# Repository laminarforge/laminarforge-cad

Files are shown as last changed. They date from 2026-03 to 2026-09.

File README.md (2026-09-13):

# laminarforge-cad

Parametric CAD models for the LaminarForge open-source diagnostics platform, written in Rust using the [`vcad`](https://crates.io/crates/vcad) crate. Core LAMP/CRISPR device CAD is now built around a sealed disposable diagnostic cartridge rather than loose PCR tubes. Shared constants live in `src/lib.rs`, device and validation generators live in `src/bin/`, and PCB routing lives in `src/pcb/`.

## Local iteration

Use the local `laminarforge_build` MCP tool with an explicit `bin`:

| Change | Action | Purpose |
| --- | --- | --- |
| Rust source validation | `check` | Check one target without code generation. |
| Rust source needs execution | `run`, profile `dev` | Build and run one target. |
| Runtime TOML only, executable already built from the intended source | `execute`, profile `dev` | Generate outputs without invoking Cargo. |
| Final optimized output | `run`, profile `release` | Explicitly optimize the selected target. |

The priming fixture accepts runtime TOML. Other models vary: some already read
configuration, while others use compiled constants. See [the iteration guide](docs/cad-iteration.md)
for exact tool arguments and verification requirements, and [the workflow audit](docs/cad-workflow-audit-2026-09-13.md)
for the remaining improvements.

## Source and delivery

`main` is canonical. Builds and CAD generation run locally on the Mac. AWS,
GitHub Actions and Namespace processing are retired; GitHub stores source only.
Pushing or tagging does not build or publish model outputs. Validate each
changed model and deliver its explicit output files through the local workflow.
PCB manufacturing output must also pass the [routing and release standard](docs/pcba_routing_and_release_standard.md).

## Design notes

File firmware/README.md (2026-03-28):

# LaminarForge Liquid Handler - FluidNC Firmware

ESP32-S3 firmware configuration for the 4-axis liquid handling robot.

## Hardware Overview

| Component | Specification |
|---|---|
| MCU | ESP32-S3 DevKitC |
| Drivers | 4x TMC2209 (UART mode, shared bus) |
| PSU | 24V |
| Axes | X, Y (belt), Z (geared belt 3:1), I (lead screw syringe) |

## Pin Assignments

### TMC2209 UART Bus (shared single-wire)

| Signal | GPIO |
|---|---|
| UART TX | GPIO 17 |
| UART RX | GPIO 18 |

All four TMC2209 drivers share this UART bus. Each driver is addressed individually (addr 0-3).

### X-Axis (Belt-driven gantry)

| Signal | GPIO | TMC2209 Addr |
|---|---|---|
| Step | GPIO 6 | 0 |
| Direction | GPIO 5 | |
| Enable | GPIO 7 | |
| Limit (min) | GPIO 4 | |

### Y-Axis (Belt-driven gantry)

| Signal | GPIO | TMC2209 Addr |
|---|---|---|
| Step | GPIO 8 | 1 |
| Direction | GPIO 16 | |
| Enable | GPIO 9 | |
| Limit (min) | GPIO 15 | |

### Z-Axis (Geared belt, 3:1 reduction)

| Signal | GPIO | TMC2209 Addr |
|---|---|---|
| Step | GPIO 12 | 2 |
| Direction | GPIO 11 | |
| Enable | GPIO 13 | |
| Limit (min) | GPIO 10 | |

### I-Axis (Syringe plunger, T8x2 lead screw)

| Signal | GPIO | TMC2209 Addr |
|---|---|---|
| Step | GPIO 47 | 3 |
| Direction | GPIO 21 | |
| Enable | GPIO 48 | |
| Limit (min) | GPIO 14 | |

### Auxiliary Pins

| Function | GPIO | Notes |
|---|---|---|
| Probe | GPIO 38 | ADC1-capable, for liquid level detection |
| Valve 1 (flood) | GPIO 39 | Solenoid valve control |
| Valve 2 (mist) | GPIO 40 | Solenoid valve control |
| Status LED | GPIO 41 | Digital output 0 |
| Error LED | GPIO 42 | Digital output 1 |
| I2C SDA | GPIO 1 | Reserved for sensors |
| I2C SCL | GPIO 2 | Reserved for sensors |

### Avoided Pins

The following ESP32-S3 strapping pins are intentionally NOT used:

- **GPIO 0** - Boot mode strapping pin
- **GPIO 3** - JTAG strapping pin
- **GPIO 45** - VDD_SPI voltage strapping pin
- **GPIO 46** - Boot mode / log output strapping pin

## Steps/mm Calculations

All axes use 200 steps/rev motors with 16 microsteps (3200 steps/rev).

| Axis | Mechanism | Calculation | Steps/mm |
|---|---|---|---|
| X | GT2 20T belt | 3200 / (pi x 12.73mm) = 3200 / 39.98 | **80.04** |
| Y | GT2 20T belt | Same as X | **80.04** |
| Z | GT2 20T + 3:1 gear | 80.04 x 3 | **240.12** |
| I | T8x2 lead screw | 3200 / 2mm lead | **1600.00** |

## Syringe Calibration

Hamilton 1710RN 100uL syringe:

- Barrel inner diameter: 1.46mm
- Barrel cross-section area: pi x (0.73)^2 = 1.674 mm^2
- Travel per microliter: 1 mm^3 / 1.674 mm^2 = **0.597 mm/uL**
- 30mm mechanical travel = ~50.2 uL usable volume
- 1 step = 1/1600 mm = 0.000625 mm = **0.00105 uL** (sub-nanoliter resolution)

## Motion Parameters

| Axis | Max Speed | Acceleration | Max Travel |
|---|---|---|---|
| X | 100 mm/s (6000 mm/min) | 500 mm/s^2 | 300 mm |
| Y | 100 mm/s (6000 mm/min) | 500 mm/s^2 | 300 mm |
| Z | 50 mm/s (3000 mm/min) | 200 mm/s^2 | 100 mm |
| I | 5 mm/s (300 mm/min) | 100 mm/s^2 | 30 mm |

The I-axis uses deliberately low acceleration and speed to prevent bubble formation and ensure precise dispensing.

## Homing Sequence

All axes home to their minimum (negative) position in this order:

1. **Cycle 1 - X-axis**: Homes to min via microswitch on GPIO 4
2. **Cycle 2 - Y-axis**: Homes to min via microswitch on GPIO 15
3. **Cycle 3 - Z-axis**: Homes to min (retracted/up) via microswitch on GPIO 10
4. **Cycle 4 - I-axis**: Homes to min (plunger fully retracted) via microswitch on GPIO 14

Z homes before I so the pipette tip is safely raised before the syringe retracts. The I-axis uses a very slow homing speed (1 mm/s feed) to avoid damaging the syringe or creating excessive vacuum.

## Flashing FluidNC to ESP32-S3

### Prerequisites

- Python 3.8+
- `esptool.py` (`pip install esptool`)
- FluidNC firmware binary (download from [FluidNC releases](https://github.com/bdring/FluidNC/releases))
- USB-C cable connected to ESP32-S3 DevKitC

### Step 1: Erase flash

```bash
esptool.py --chip esp32s3 --port /dev/tty.usbmodem* erase_flash
```

### Step 2: Flash FluidNC firmware

```bash
esptool.py --chip esp32s3 --port /dev/tty.usbmodem* \
  --baud 460800 \
  write_flash \
  0x0000 bootloader.bin \
  0x8000 partitions.bin \
  0x10000 firmware.bin \
  0x3d0000 spiffs.bin
```

Alternatively, use the FluidNC WebUI installer at [http://install.fluidnc.com](http://install.fluidnc.com) for a browser-based flash.

### Step 3: Upload configuration

1. Connect to the `LaminarForge` WiFi AP (password: `laminarforge`)
2. Open `http://192.168.0.1` in a browser
3. Navigate to the **Files** tab in the FluidNC WebUI
4. Upload `fluidnc_config.yaml` as the machine config
5. Restart the ESP32 (or send `$Bye` then power cycle)

Alternatively, upload via serial:

```bash
# Using FluidNC's built-in file upload over serial
# Connect at 115200 baud, then use $LocalFS/Upload command
picocom -b 115200 /dev/tty.usbmodem*
```

### Step 4: Verify

After reboot, connect via serial or WebUI and check:

```
$SS   # Show settings summary
$$    # Show all settings
$H    # Home all axes (ensure limit switches are wired)
?     # Status report
```

## TMC2209 UART Wiring

The four TMC2209 drivers share a single UART bus. Each driver must have its
address pins (MS1, MS2) set to give it a unique address:

| Driver | Axis | MS1 | MS2 | Address |
|---|---|-----|-----|---|
| U1 | X | LOW | LOW | 0 |
| U2 | Y | HIGH | LOW | 1 |
| U3 | Z | LOW | HIGH | 2 |
| U4 | I | HIGH | HIGH | 3 |

The UART TX pin connects to all four PDN_UART pins through 1k ohm resistors.
The UART RX pin connects to all four PDN_UART pins directly (active-low
open-drain outputs on the TMC2209 side).

## Troubleshooting

- **Motors don't move**: Check 24V supply, verify enable pins are being driven LOW (active low on TMC2209)
- **Erratic motion**: Verify UART addresses match MS1/MS2 pin settings on each driver
- **Homing fails**: Check limit switch wiring (normally open, pulled up internally). Verify with `?` status that switch state changes when actuated
- **Syringe stalls**: Reduce I-axis run current or increase stallguard threshold. The lead screw has inherent friction that can trigger false stall detection
- **WiFi won't connect**: The AP defaults to `LaminarForge` / `laminarforge`. If reconfigured for STA mode, check SSID and password in the YAML

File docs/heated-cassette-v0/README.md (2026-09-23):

# LaminarForge heated microplate cassette V0 - Rev D

This package defines one manual, two-zone heated aluminum cassette for water-filled microplate temperature testing. Manufacture to the analytic STEP files together with the shop drawings and manufacturing notes. STLs and assembly images are viewing aids. The physical prototype still needs commissioning and temperature mapping.

Greiner 655101 with lid 656101 is the selected inexpensive thermal surrogate. It is not a perfused tissue-on-chip plate. No live-cell suitability, sterile atmosphere, humidity control, CO2 control, hermetic seal, rocking endurance or media-temperature performance is certified here.

## Fabrication and assembly

Send the complete supplier RFQ ZIP, including assembly-drawings.pdf, the numbered assembly/manufacturing BOMs, shop-drawings.pdf and the assembly handbook, to a CNC shop. Request one set, 6061-T6, including clear Type II finishing and the limited fit-dimension report. Buy the commercial mechanical/electrical parts from the BOM. Assembly needs metric hex tools, a small torque driver, multimeter, suitable connector crimp tooling, solder/heat-shrink supplies and temperature-measurement equipment.

One representative spacer file specifies eight identical spacers. Both guards, both risers and both cable jaws are identical after translation. The left guide rail has an extra stop-access hole. The cable-bracket bases differ.

## Design definition

- Four-piece bolted frame (roof, left/right side plates, front bezel), rear cover, heated sliding bottom, front flange and removable nest.
- Two manual M4 closure knobs; continuous silicone face gasket; metal face-to-face closing stop.
- Two 100 x 100 mm, 24 V, 60 W heaters with separate Pt100 sensors, PIDs and DC SSRs.
- Independent NC thermostats drop latched power relays. Shared STOP and separate zone RESET buttons.
- Guide tape on edges only. The plate sits directly on the aluminum drawer.
- Rearward R35 cable loops and 30 mm bench risers; keep the service bay clear.

Housing/flange envelope: 197.26 W x 176.73 D x 75.225 H mm. Complete bench assembly is approximately 95.225 mm high, Z=-30 to +65.225 including upper screw heads. Reserve 120 mm forward of the closed front for drawer access and space through Y=270 behind the assembly datum for cable travel. Closed outer front is Y=-8. Controller box and power brick are separate.

The closure knobs project another 11.5 mm forward and remain within the wider 197.26 mm flange width. With the reserved rear cable bay, allow approximately 290 mm closed bench depth, plus the forward drawer-access space. See the generated thermal-sizing.json for the current aluminum mass. This is a bench arrangement, not a finalized rack pitch.

Nominal stroke is 107.73 mm. Rear aluminum capture is 45 mm; the shortened left upper tape retains 29 mm overlap. The flange defines closing position. The stop slot allows approximately 0.2 mm pin clearance beyond nominal travel.

## Plate fit

Greiner's 655101 drawing specifies 127.76 +/-0.20 x 85.48 +/-0.20 mm footprint and 14.6 +/-0.1 mm lidless height. The nest opening is 129.26 x 86.98 mm with corner reliefs. Minimum centered side clearance is 0.65 mm at the plate's upper tolerance, before nest manufacturing tolerance.

Lid 656101 is 127.5 +/-0.2 x 85.0 +/-0.2 mm. Its drawing shows 10 mm overall lid features but does not certify assembled plate/lid height. This design reserves a 26 mm lidded object plus 8 mm roof clearance. The 26 mm value is a design allowance, not the actual Greiner assembled height. Measure the delivered lidded plate. Future tissue plates need separate exterior, lid, port, orientation, access and rocking checks.

## Rev D changes

Rev D replaces the unsent integral Rev C housing with four bolted plates. Side plates finish at 18.50 mm from nominal 3/4-inch stock; roof and bezel finish at 6 mm from 1/4-inch stock. The body grows 12.50 mm in width while the drawer, plate clearances and stroke remain unchanged. Six roof screws, four recessed bezel screws and six locating dowels join the frame. Assembly drawings, BOMs and individual STEP files describe the separate parts. Joint contact resistance and thermal behavior require physical commissioning.

Rev A hardcoat is superseded by clear sealed Type II anodizing, 5-15 micrometers. The quote covers 26 aluminum pieces in 16 designs per set. Foam, backing, guide tape, hardware and electronics are owner supplied. Per-part prices and a separate finishing charge are sufficient; operation-level costing is not required. The integral housing is replaced by four plates, located by dowels and fastened with M3 screws.

## Verification and file precedence

The generator uses one construction tree for analytic STEP and review meshes. It reimports every custom STEP, checks one manifold solid, compares volumes and records hashes. It checks closed meshes and sampled moving/fixed interference. Packaging separately imports every supplied STEP into the installed Open CASCADE DRAW checker, checks exact shape validity and one solid, and retains the result logs. This is a separate version/import path, not proof that every supplier CAD system will accept the file. These checks do not establish fatigue, deformable-part behavior, process capability or electrical certification.

The reduced thermal model estimates steady aluminum-sheet conduction over assumed heat-loss/conductivity cases. It does not resolve media, plastic wells, evaporation, airflow or PID transients. Water measurements decide thermal acceptance.

Use configuration, verification manifest, STEP and drawings from the same release. Explicit thread and manufacturing notes control where STEP represents pilot bores; paired STEP controls other geometry. Resolve conflicting instructions before cutting an affected part. Integrated mechanical instructions supersede preliminary research arrangements.

## Sources

Plate: https://hamptonresearch.com/uploads/support_materials/HR3-139_Greiner_655101_customer_drawing.pdf

Lid: https://shop.gbo.com/en/usa/products/bioscience/lids-sealers-capmats/lids/656101.html

Lid drawing: https://www.bunzlasiapacific.com/extension/IP/document_896_5bfca99a5b406.pdf

Component sources are linked in the BOM/electrical appendices. Prices are snapshots, not a complete landed cost or a CNC quote.

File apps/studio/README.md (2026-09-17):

# LaminarForge Studio

Local macOS design review app written in Rust. Open a folder of generated STL
files, search the library, inspect a mesh, and export the current view as PNG.
The app uses an OpenGL depth buffer and GPU triangle rendering through eframe.
It requires macOS 12 or later. Build on the target Mac architecture.

## Use

- Select **Funding** to edit the prototype grant proposal, expense budget and submission checklist. The initial application ships with the app.
- Funding edits persist locally, including in the sandboxed TestFlight app. Use
  **Save changes** to save immediately; normal autosave runs every five seconds and
  on app exit. Funding content is independent of CAD folder permissions.
- Copy individual application fields and open the provider form when ready.
  The app does not submit applications. The initial round covers fabrication, assembly and water-based thermal validation; no lab access is required. Budget allowances are provisional.
- **Supplier quotes and equipment prices** shows dated research, source links,
  sent RFQ threads and unresolved costs. The catalog subtotal excludes unpriced
  items and optional candidates. It does not replace the complete funding budget.
  This bundled snapshot is refreshed with app updates independently of saved
  proposal edits; it does not poll Gmail or automatically send follow-ups.

- Open **LaminarForge Studio.app**, then **Open folder…** or **Open design…**.
- A dropped STL file or directory also opens in the workspace.
- Drag to orbit; right/middle drag to pan; scroll to zoom.
- Press **F**, double-click the viewport, or use **Fit design** to reframe.
- Choose shaded, shaded with edges, or hidden-surface wireframe.
- Use the inspector for orthographic projection and top/front/isometric views.
- **Export PNG…** saves only the render viewport at its current pixel size.
- **Refresh library** rescans disk; **Reload design** reloads changed geometry.

The local development app remembers its library and design. The sandboxed
TestFlight app starts with an empty library each launch; select a folder or file
with the Open controls to grant access for that session. There is no network service,
cloud processing, or account requirement. Diagnostics use structured tracing on
stderr. An optional first CLI argument opens a file or folder at launch.

## Supported geometry

ASCII and binary STL are supported. Files are never modified. Bounds report
source coordinate units: STL does not record units; LaminarForge generators
normally use millimeters. Invalid files and non-finite coordinates report errors.
Zero-area faces are omitted and counted. Limits are 150 MB per file, two million
triangles, 10,000 library files and 16 folder levels. Directory scans skip symbolic
links, hidden folders, target and node_modules. Permission failures are explicit.

This first version renders existing meshes. It does not edit CAD parameters,
generate new geometry, import STEP directly, or validate manufacturing readiness.
Generate STL with the existing CAD tools before opening it here.

## Local build and delivery

This is a separate Cargo package so desktop dependencies do not affect the CAD
generators. Use `laminarforge_build` with `repo: "laminarforge-cad"`, `repo_path`
set to this `apps/studio` directory, `bin: "laminarforge_studio"` and action
`check` or `build`. Select `profile: "dev"` for iteration. Cargo.lock is tracked.

For a local app bundle, use the same MCP tool with `bin: "studio_bundle"`, action
`run`, and args `[BUILT_STUDIO_EXECUTABLE, NEW_OUTPUT_APP_PATH]`. The packager
creates the icon, plist and executable, ad-hoc signs the bundle, and verifies
the signature. Output must be a fresh `.app` path. This is a local Mac build,
not an Apple-notarized download or a TestFlight release.

For parser tests, run `cargo test --locked --bin laminarforge_studio -j 2` from
this directory; the CAD MCP currently exposes no test action.

To verify actual GPU rendering use MCP `run`, `background: true`, with args:

```text
--render-check INPUT_STL_OR_FOLDER FRESH_OUTPUT.png edges
```

The last argument is optional: `shaded`, `edges`, or `wireframe`. This opens the
real window, loads the geometry, captures the rendered framebuffer, writes the
viewport PNG plus `FRESH_OUTPUT.workspace.png`, and exits. A missing PNG is an
error. Inspect the capture as well as the exact background job status. Use a
fresh output filename for every check. UI automation and full interaction tests
remain separate from the framebuffer check.

## TestFlight

The macOS target in `project.yml` packages the Rust executable for Apple Silicon.
Build `laminarforge_studio` with the local CAD MCP and `features: ["app-store"]`.
Stage that build receipt's executable as `dist/laminarforge_studio` and generate
`dist/laminarforge_studio.sha256` using `shasum -a 256 laminarforge_studio` from
`dist`. Xcode verifies the checksum before installing the executable into its
app bundle, then signs with the Studio Mac App Store provisioning profile.
The profile and signing credentials are machine configuration, never repository
files. `ExportOptions.plist` selects App Store Connect distribution.

Submit with `macos_deploy`, app `laminarforge-studio-macos`. The Mac-local
pipeline allocates the build number, generates the Xcode project, archives,
exports the signed installer and uploads to TestFlight. No cloud build is used.

The initial verification used the heated-cassette V0 design library (20 files)
and closed/open assemblies. The closed assembly rendered 11,866 triangles.
Desktop-control verification was unavailable because the Sky native pipe failed
to start; framebuffer verification exercised actual native rendering and export.

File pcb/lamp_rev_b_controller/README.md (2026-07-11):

# LAMP Rev B Controller PCBA

Source-package ticket: `T-4C206871`<br>
Manufacturer-handoff ticket: `T-E36FA2C2`<br>
Electrical release evidence: `A-9F7C4851`

This directory is the deterministic source for the Rev B controller carrier. The promoted copper/electrical design is fabrication-clean. Manufacturer-order readiness is a separate fail-closed state owned by `lamp_rev_b_controller_fab_release`.

## Routing and release policy

All routing and manufacturer-release work is governed by the mandatory [LaminarForge PCBA Routing and Release Standard](../../docs/pcba_routing_and_release_standard.md). The board-specific fixture and evidence are:

- [`freerouting_benchmark.toml`](freerouting_benchmark.toml): pinned router/tool settings and the 1,200-second runtime cap;
- [`freerouting_benchmark.md`](freerouting_benchmark.md): harness operation and determinism limitations;
- [`benchmarks/freerouting_v2_1_0_pass_sweep.md`](benchmarks/freerouting_v2_1_0_pass_sweep.md) and its [JSON record](benchmarks/freerouting_v2_1_0_pass_sweep.json): exact 1→10→50 matrix evidence;
- [`benchmarks/freerouting_v2_1_0_promotion.md`](benchmarks/freerouting_v2_1_0_promotion.md): first-clean promotion-attempt evidence; and
- [`electrical_release_evidence.md`](electrical_release_evidence.md), [`fab_release.toml`](fab_release.toml), and [`release_manifest.toml`](release_manifest.toml): electrical, fabrication, and deterministic-package gates.

These files specialize the general policy for Rev B; they do not replace it. Routing and SES validation remain scratch-only until every promotion gate passes.

## Locked first-article population

- Variant: `rev_b_12v_first_article`; 5 assembled top-side PCBAs.
- `R25` and `R26`: mandatory DNP. Populating either bypasses its heater MOSFET and can energize the heater whenever `VIN_HEATER` is present.
- `R55`: populate only for this 12 V variant; DNP for 24 V unless an approved regulated 12 V VDRV path is present.
- `J24`: connect through an external normally-closed thermal cutoff or a correctly rated jumper before heater tests. Do not bridge `VIN_PROTECTED` to `VIN_HEATER` in copper.
- `LDD-1000H` and `P7812-500R` alternates: DNP for this release.
- Panelization: fabricator-owned from the released single-up board; portal preview approval is mandatory.

## Authoritative workflow

Run the repository contract and release command through the LaminarForge build tool:

```json
{"repo":"laminarforge-cad","action":"run","bin":"lamp_rev_b_controller_check"}
```

```json
{"repo":"laminarforge-cad","action":"run","bin":"lamp_rev_b_controller_fab_release"}
```

The release command requires a clean full commit equal to `origin/main` and KiCad `10.0.3`. It writes every KiCad report/export to two ignored temporary trees, normalizes known time metadata, compares every staged byte, and promotes only identical results.

When every external choice is controlled, it emits:

- nine fabrication Gerbers plus the Gerber job file;
- separate F/B paste Gerbers;
- separate PTH/NPTH Excellon drills, both drill maps, and drill report;
- fabrication and top/bottom assembly PDFs;
- formal BOM, CPL, DNP, and no-substitution CSVs;
- schematic PDF, top/bottom renders, board-only mechanical STEP, source snapshot, notes, and electrical evidence;
- `MANIFEST.json`, `SHA256SUMS`, upload units, and a normalized outer handoff ZIP.

If procurement, stackup/order fields, or portal approval remain unresolved, it still preserves the byte-reproducible review tree and exact blocker report, exits nonzero, and emits neither `upload/` nor the outer handoff ZIP.

## Current external blockers

Repository evidence does not define a selected manufacturer/order profile, physical dielectric stackup, fabrication tolerances/class, final finish specification, colors, or an impedance-policy decision. `parts.toml` also lacks explicit manufacturer/MPN fields and contains unresolved supplier prose/manual selections. No portal preview has been approved. These are manufacturing choices, not electrical design defects; do not invent them and do not treat the provisional artifact `A-D87AC12B` as vendor-cited research.

Any source, population, placement, schematic, stackup, or copper change invalidates prior evidence and requires fresh DRC/connectivity/ERC/BOM/CPL/reproducibility gates.

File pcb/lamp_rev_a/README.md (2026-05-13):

# LaminarForge LAMP Rev A PCBA

This directory is the source package for the real one-board LAMP PCBA.

The goal is one 4-layer ESP32-S3 board that can be checked, laid out in KiCad,
exported for JLCPCB, and iterated without going back to the old generated-layout
workflow.

## Source Of Truth

- `contract.toml`: board requirements, rails, nets, GPIO map, test points, and verification gates.
- `parts.toml`: selected schematic parts plus explicit fab-blocking part-selection gaps.
- `power_architecture.toml`: locked Rev A power topology and the explicit no-buck decision.
- `optical_architecture.toml`: locked Rev A optical topology, wavelength, detector, and front-end decision.
- `optical_mode.md`: human-readable optical-mode decision and bench validation gate.
- `placement.toml`: locked starting refs, coordinates, test points, and eight-slot optical geometry.
- `pin_nets.toml`: conservative footprint pad-to-net assignments for known package pinouts.
- `firmware_handoff.toml`: ESP32-S3 module-pin to SoC-GPIO handoff, slot map, and firmware bring-up notes.
- `electrical_validation.toml`: pre-fab electrical validation assumptions, derating gates, current-path checks, and simulation handoff sources.
- `routing_plan.toml`: routing phase order, current unrouted count, autorouter policy, and release gates.
- `routing_seed.toml`: DRC-clean starter traces emitted into the materialized board.
- `copper_zones.toml`: controlled KiCad copper pours, starting with front/back GND zones.
- `fab_release.toml`: repeatable KiCad CLI export contract for Gerbers, drill files, assembly files, STEP, and release reports.
- `lamp_rev_a.kicad_sch`: KiCad schematic shell for the one-board Rev A electrical architecture.
- `lamp_rev_a.kicad_pcb`: materialized KiCad board with the Rev A outline, 4-layer stack, placed footprints, test points, and optical-slot guides.
- `lamp_rev_a.kicad_pro`: KiCad project shell.
- `sym-lib-table` / `fp-lib-table`: project-local library tables pointing at the locked `pcb/lib/lcsc` symbols and footprints.
- `lamp_rev_a.kicad_dru`: custom KiCad design rules for power, heater, analog, and USB constraints.
- `kibot.yaml`: intended fab/report export pipeline once the schematic and placed board exist.

Rust should validate contracts and automate exports. KiCad should own the
schematic and PCB layout.

## Iteration Flow

```text
contract.toml + parts.toml
  -> cargo run --release --bin lamp_pcba_check
  -> placement.toml refs and zone checks
  -> pin_nets.toml trusted pad assignments
  -> firmware_handoff.toml firmware pin/slot handoff checks
  -> electrical_validation.toml power, derating, heater, GPIO, USB, and simulation checks
  -> cargo run --release --bin lamp_rev_a_materialize_board
  -> cargo run --release --bin lamp_rev_a_seed_routes_from_drc when reseeding short safe traces
  -> cargo run --release --bin lamp_rev_a_route_greedy for DRC-gated route iteration
  -> kicad-cli pcb drc --refill-zones for zone-connected routing checks
  -> KiCad schematic capture in lamp_rev_a.kicad_sch
  -> KiCad ERC
  -> footprint/BOM/JLC field lock
  -> KiCad placement cleanup from the materialized board
  -> KiCad interactive routing
  -> KiCad DRC + schematic/PCB parity
  -> KiBot/KiKit fab outputs
  -> physical bring-up measurements
  -> update contract.toml for the next revision
```

## Board Decisions

- One physical board for Rev A.
- 4-layer stack: `F.Cu`, `In1.Cu` ground plane, `In2.Cu` power plane, `B.Cu`.
- ESP32-S3 module, not a bare ESP32 chip.
- USB VBUS is the Rev A electronics 5 V source through a Schottky path; +3V3 is derived locally.
- The 12 V input is reserved for heater power. Do not add a 12 V to 5 V buck unless standalone non-USB operation becomes a new explicit Rev change.
- External heater element driven from the board through a protected high-current output.
- Heater path protection is locked as board-side resettable fuse + TVS + 5.08 mm heater terminal, with an external inline KSD9700 thermal cutoff mounted on the heater assembly.
- Optical mode is locked to 650 nm red-light turbidimetry with eight LED/photodiode channels, muxed into one TIA and ADC path.
- Starting placement is locked in `placement.toml`: 91 top-side footprints, 16 test points, and 8 optical slots at 12 mm pitch.
- Test points are mandatory for rails, heater control/output, I2C, UART, boot/reset, ADC, and mux output.

## Local Checks

Run:

```bash
cargo run --release --bin lamp_pcba_check
cargo run --release --bin lamp_rev_a_electrical_validate
cargo run --release --bin lamp_rev_a_spice_check
cargo run --release --bin lamp_rev_a_materialize_board
cargo run --release --bin lamp_rev_a_fab_preview
cargo run --release --bin lamp_rev_a_fab_release
cargo run --release --bin lamp_rev_a_route_report
cargo build --release --bin lamp_rev_a_materialize_board --bin lamp_rev_a_route_greedy
LAMP_ROUTE_MAX_ACCEPTS=10 LAMP_ROUTE_MAX_TRIALS=160 target/release/lamp_rev_a_route_greedy
```

`lamp_rev_a_spice_check` requires `ngspice`. `main` CI installs it, runs the
operating-point check against the generated power-path netlist, then runs
`lamp_rev_a_fab_release` on a KiCad-enabled macOS runner and uploads
`lamp-rev-a-pcba-fab-release-<commit>` containing the validated fab release
directory and upload bundles.

The current schematic is an architecture shell, not a fabrication-ready circuit.
The checker should not report fab-blocking part-selection gaps. The board now
materializes all selected parts into KiCad with zero physical DRC violations
with a DRC-clean starter route seed and GND copper pours. The route seed is
currently at 112 accepted segments, zero real unrouted ratlines after KiCad zone
refill, and one ignored KiCad self-zone report item for the front GND pour. The
active work is schematic completion, schematic/PCB parity, fab export validation,
and bench validation.
`lamp_rev_a_fab_release` emits JLCPCB machine-assembly BOM/CPL files separately
from through-hole/manual-install parts, then verifies that required Gerbers,
drills, reports, position files, review STEP output, and the order audit report
are present and non-empty. It also emits validated upload bundles under
`fab_release/bundles/`: fabrication Gerbers/drills, assembly CSVs, and review
artifacts. The release also includes a source snapshot bundle with the exact
KiCad and TOML inputs used to generate the fab package. The review package
includes a bring-up checklist generated from the configured Rev A test points
and a firmware handoff generated from the checked ESP32-S3 pin map. It also
emits an electrical-validation report, a first-order SPICE power-path handoff,
a machine-checked full-speed USB DP/DN routing sanity gate, a
simulation/analysis handoff, generated PDN current-path and thermal power CSVs,
a structured first-article measurement CSV for current-limited rail bring-up,
component derating/stress CSVs for the high-risk electrical parts,
an EMC/ESD pre-compliance CSV for USB, heater, 12 V, Wi-Fi, and analog noise risks,
a USB-C power-budget CSV for Rd/default-current, VBUS/+5V/+3V3 current, inrush linkage, and first-article rail coverage,
a procurement-readiness CSV for critical part ordering, machine/manual assembly, and external safety-component evidence,
a procurement-substitution CSV locking safety-critical LCSC order codes and requiring engineering review for swaps,
a schematic source/parity CSV tying the architecture-shell KiCad schematic to contract modules, selected parts, and required nets,
a connector/polarity CSV for USB-C, manual connectors, diodes, MOSFETs, and orientation-sensitive IC pinouts,
an assembly-orientation CSV for machine-placed ICs, polarity-sensitive parts, CPL centroids, and pin-1 evidence,
an assembly-inspection CSV requiring AOI/photo evidence, linked validation gates, and stop/rework actions for critical parts,
an assembly-fixture/readability CSV requiring visible silkscreen labels, fixture references, photo evidence, and rework actions for critical connectors/test points,
a machine-checked assembly-parity CSV for BOM/CPL/manual/position reference consistency,
a fabrication-capability CSV for board-house stackup, geometry, drill, via, and routing process limits,
an I2C/ADS1115 bus validation CSV for pull-up, rise-time, device identity, and stuck-low coverage,
a heater-protection coordination CSV for PTC, terminal, MOSFET, TVS, external cutoff, and current-limit coverage,
an external-harness safety CSV for 12 V adapter, heater leads, inline cutoff, wire gauge, polarity, and strain relief,
a mechanical-access CSV for service connector, heater terminal, MOSFET, boot/reset, analog, and I2C probe reachability,
an ESP32-S3 startup-safety CSV for boot straps, reset, and heater fail-closed defaults,
a manufacturing-test coverage CSV for critical test points, firmware diagnostics, and release traceability,
a calibration-readiness CSV for heater, ADC, optical, sensor-bus, negative-control, and firmware identity records,
a validation-traceability CSV tying each gate to artifacts, manifest evidence, CI steps, and pass criteria,
a simulation-input CSV for PDN, electrothermal, USB/SI, and EMC handoff readiness,
the first routed-geometry DC PDN simulation CSV for voltage drop and I2R loss,
a lumped thermal-margin simulation CSV for component and routed-copper steady-state estimates,
a heater/reaction-block thermal transient CSV for warm-up, hold, duty, overshoot, and energy estimates,
an ngspice ESP32-S3 reset/boot-strap timing netlist/CSV for EN, GPIO0, and boot-sensitive output startup checks,
an ngspice USB/VBUS hot-plug and 3.3 V startup/inrush netlist/CSV for rail startup envelope checks,
an ngspice 3.3 V rail load-step transient netlist/CSV for ESP32 burst-load sag,
an ngspice power-domain fault/backfeed netlist/CSV for 12 V heater-domain isolation assumptions,
an ngspice optical analog front-end transient netlist/CSV for TIA/ADC signal-envelope range,
an optical crosstalk/mux-settling CSV for slot isolation and ADC sampling assumptions,
an optical signal/noise margin CSV for threshold and negative-control drift assumptions,
and a thermistor/ADC transfer CSV for heater temperature-sense range, sensitivity, and fault coverage,
and a checksum manifest for the fabrication, assembly, and source bundles.
It also mirrors the board STEP review model to `output/lamp_rev_a_board.stp`;
run the CAD conversion for `lamp_rev_a_board` to create
`output/lamp_rev_a_board.usdz` for the Agentic FlowState CAD tab.

Current KiCad checks:

```bash
kicad-cli sch erc pcb/lamp_rev_a/lamp_rev_a.kicad_sch \
  -o pcb/lamp_rev_a/reports/erc.json --format json

kicad-cli pcb drc --refill-zones --format json \
  --output pcb/lamp_rev_a/reports/drc.json \
  pcb/lamp_rev_a/lamp_rev_a.kicad_pcb
```

Expected DRC state at this stage: `0 violations` and no real unrouted
connections. KiCad may still report one self-referential front-GND-zone
`unconnected_items` entry; `lamp_rev_a_route_report` ignores only that exact
self-zone artifact and still reports real ratlines by net.

`lamp_rev_a_seed_routes_from_drc` is intentionally conservative: it only seeds
short direct routes that preserve zero physical DRC violations. Longer routes
must be added deliberately in `routing_seed.toml`, accepted by
`lamp_rev_a_route_greedy`, or finished in KiCad. `lamp_rev_a_route_greedy`
mechanically tries candidate routes, runs KiCad DRC, and keeps only candidates
that reduce `unconnected_items` while preserving zero physical DRC violations.

Do not accept autorouter output by itself. Use it to expose bad placement or
constraint problems, then finish and review the layout in KiCad.

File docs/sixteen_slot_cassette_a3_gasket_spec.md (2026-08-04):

# 16-Slot Cassette A3 Gasket Subsystem Spec

Ticket: T-3ABDE2C9

This is the gasket subsystem specification for the first physical LaminarForge 16-slot AAV cassette build. It is subordinate to `docs/sixteen_slot_cassette_a0_interface_spec.md`; if this document conflicts with A0, A0 controls until the cassette integrator updates the interface contract.

This is not a sterile-barrier claim, biological release criterion, or final production drawing. It defines the first-article gasket geometry, material candidates, compression evidence, and no-cell validation gates needed before manufacturer drawings and live-cell/AAV work.

## Scope Boundary

A3 owns:

- Per-slot and perimeter gasket material direction.
- Gasket cross-section and locked nominal lid-groove dimensions.
- Compression target, compression stops, and witness shims/coupons.
- Gasket land surface finish, flatness, and cleaning-inspection assumptions.
- No-cell leak, coupon burst, and repeated gasket reassembly validation logic.
- Gasket-specific open decisions for integrator, A2 lid/clamp, A4 DFM, and validation agents.

A3 does not own carrier architecture, lid/clamp layout, disposable tubing route, port family, incubation control, or final CAD generator edits except where those features directly set gasket compression, retention, or test interfaces.

## A0 Interface Inputs

The gasket design uses these A0 locked inputs:

| Interface | A0 value |
| --- | ---: |
| Cassette format | 16 slots, 4 x 4 |
| Experimental unit | One cassette equals one AAV capsid/promoter/payload/dose/timing/media condition; seal loops do not authorize separate per-slot candidates. |
| Active CAD baseline | `sixteen_slot_cassette_incubator_first_article` |
| Carrier base body / true overall | 699.04 x 541.92 x 24.00 mm / 699.04 x 541.92 x 31.35 mm |
| Per-slot gasket land outer | 145.76 x 103.48 mm |
| Per-slot gasket land inner | 129.76 x 87.48 mm |
| Per-slot gasket land wall width | 8.00 mm |
| Per-slot gasket land height | 7.35 mm above carrier top; land face meets lid underside at closure. |
| Inter-land clearance | 6.00 mm between adjacent outer edges; all 16 loops are independent and nonoverlapping. |
| Perimeter gasket land outer | 629.04 x 459.92 mm |
| Perimeter gasket land inner | 605.04 x 435.92 mm |
| Perimeter gasket land wall width | 12.00 mm |
| Perimeter gasket land height | 7.35 mm above carrier top; common with per-slot lands and hard stops. |
| Nominal chip protrusion / closure plane | 7.35 mm above carrier top |
| Nominal gasket thickness | 2.40 mm |
| Lid groove cavity | 1.80 mm deep x 3.20 mm wide |
| Target squeeze | 25% |
| Squeeze guard band | 20-30% |
| Witness steps | 20%, 25%, 30% |
| Hard stops | Nine 4.00 mm-diameter internal stops at the 3 x 3 inter-slot intersections plus 4.00 mm-wide perimeter stops in the 5.00 mm seal-to-gutter web; all top at 7.35 mm and clear every seal. |

First-article wetted-path policy remains unchanged: disposable commercial tubing/connectors are the culture-fluid boundary. Structural cassette parts and A3 gaskets are dry structural/environmental seals unless separately validated as wetted, cell-facing, and AAV-compatible interfaces.

## Target Seal Architecture

Use controlled-compression axial face seals, not adhesive-only sealing.

The first-article gasket is a replaceable continuous elastomer seal seated in machined grooves on the lid/clamp compression side and compressed against the raised carrier gasket lands. This keeps the carrier land surfaces simple to inspect and lets the lid carry gasket retention features. At closure, the 7.35 mm carrier land faces meet the lid underside and the 1.80 mm groove cavities contain the compressed gasket; the groove location is no longer an optional A2 inversion.

Recommended first-article architecture:

| Seal loop | Function | Direction |
| --- | --- | --- |
| 16 per-slot loops | Local chip-pocket/environmental isolation and visible leak segregation by slot | One continuous loop per slot, seated over the A0 per-slot raised land. |
| Perimeter loop | Outer condensate/leak containment and environmental boundary | One continuous loop on the A0 perimeter land; do not treat this as a high-pressure chamber boundary until structural proof is complete. |
| Witness coupon loops | Process and material evidence | Same cross-section, gland depth, finish, and compression stops as production loops. |

Avoid discrete corner pieces, butt joints, hand-cut square gasket corners, or RTV-in-place sealing for the first article. If spliced cord is used, splice joints must be vendor-made or made with a documented fixture and placed on straight segments away from ports, drains, and high-observation zones.

## Material Candidates

The first material downselect is between high-purity silicone and high-purity EPDM. TPE/SEBS remains a research-backed option for integrated organ-chip microgaskets, not the default reusable cassette face seal until vendor review.

| Rank | Material | Use case | Advantages | Risks / limits | A3 disposition |
| ---: | --- | --- | --- | --- | --- |
| 1 | Platinum-cured silicone, 50-60 Shore A, USP Class VI / ISO 10993 supplier data preferred | First dry/environmental cassette gasket and witness coupons | Common medical/bioprocess gasket material, tolerant of 37 C humid incubation, available as molded seals or cord, low closure force versus harder elastomers | Gas permeability; possible absorption/adsorption if used as wetted drug/vector-contact surface; tear risk at thin sections | Baseline candidate for first quote and no-cell validation. Not approved for AAV/culture-fluid contact without extractables/adsorption review. |
| 2 | High-purity EPDM, 60-70 Shore A, USP Class VI supplier data preferred | Alternate for humid/water/cleaning exposure and higher tear margin | Good water/steam/humidity compatibility, lower gas permeability than silicone in many applications, robust reusable seal option | Less transparent; compatibility depends on cleaning chemistry; not for oils/hydrocarbons; higher closure force at 70A | Quote as alternate material and run same witness coupon tests. |
| 3 | Oil-free SEBS/TPE microgasket material | Future disposable chip-interface or integrated microgasket layer | Organ-chip literature supports reversible compression interfaces and lower small-molecule absorption than PDMS in some TPE systems | Supplier-specific; large reusable face-seal behavior and compression set must be proven; fabrication path differs from simple machined gland | Escalated to future disposable interface work, not first carrier/lid baseline. |
| 4 | FKM / FFKM | Specialty chemical-resistance gasket if cleaning chemistry forces it | Strong chemical resistance and low gas permeability options | Higher cost and closure force; cell-facing/bioprocess data must be compound-specific | Do not use for first article unless DFM/vendor review rejects silicone and EPDM. |
| Rejected baseline | PDMS | Common organ-chip elastomer | Familiar and easy to prototype | Strong small-molecule absorption risk and poor fit for AAV condition-interface assumptions | Not the first-article gasket baseline. |

Material certification required for quote package:

- Supplier, compound name, durometer, lot traceability, and sheet/cord dimensional tolerance.
- Compression set data at 37 C in humid conditions or nearest available test.
- Cleaning exposure notes for the actual planned cleaning agents.
- Extractables/biocompatibility data if any part of the gasket later becomes wetted or cell-facing.

## Cross-Section And Groove Dimensions

Baseline cross-section: 2.40 mm nominal round cord/O-ring cross-section, used as a controlled axial face seal.

This keeps A0's 2.40 mm gasket thickness and 20-30% witness range intact while using standard static face-seal gland logic. Larger cross-sections are more tolerant of flatness error but would increase clamp load and consume the current gasket lands; smaller cross-sections reduce tolerance margin. Do not change the 2.40 mm baseline without updating A0 and the witness-coupon steps.

First-article gland dimensions:

| Parameter | Baseline value | Notes |
| --- | ---: | --- |
| Gasket cross-section / free height | 2.40 mm nominal | Supplier tolerance target +/-0.08 mm or better. |
| Target compressed height | 1.80 mm | 25% squeeze. |
| Acceptable compressed-height band | 1.68-1.92 mm | 30-20% squeeze guard band. |
| Lid groove depth | 1.80 mm | Locked nominal cavity depth for 2.40 mm axial seal at 25% squeeze. Supplier tolerance and groove-fill evidence remain required. |
| Lid groove width | 3.20 mm | Locked nominal width; leaves expansion volume and fits within the opposing A0 land widths. |
| Lid groove floor | 2.20 mm minimum in active CAD | A 4.00 mm continuous underside seal skin minus the 1.80 mm groove; the 6.00 mm upper lightening relief may not penetrate this skin. |
| Chip-relief-to-groove material | 2.20 mm per side in X and Y | The 130.16 x 87.88 mm chip-top relief must not break into the per-slot groove. |
| Groove side finish | 1.6 um Ra max | Deburred; no tool marks that cut the seal. |
| Seal land top/bottom finish | Ra 0.8 um target; Ra 1.6 um hard maximum | Liquid/no-cell leak validation. A vendor may require a smoother finish. Use Ra 0.4 um max if gas/vacuum retention becomes a requirement. |
| Groove entry radius / break | 0.20 mm min | No sharp edges at gasket entry. |
| Seal-loop corner radius | 3.0 mm min centerline radius | Larger preferred; no square elastomer corners. Confirm with gasket vendor. |
| Groove fill check | Vendor-calculated before drawings | Must leave expansion volume at temperature and after media/cleaning exposure. |

The current STL and STEP drafts use square-cornered subtraction loops and do
not model the 0.20 mm entry break. They are internal envelope/fit-check
geometry only. D2/D4 manufacturing geometry must add the entry break and at
least 3.0 mm groove-centerline corner radii before gasket coupon fabrication or
vendor RFQ.

Per-slot fit on the 8.00 mm A0 land:

- 3.20 mm lid groove aligned to the center of the opposing carrier land.
- Minimum 2.0 mm nominal machined land margin on each side after groove placement.
- No groove overlap into optical keepout, chip pocket edge, label land, drain feature, or fastener clearance.
- Preserve each 145.76 x 103.48 mm outer / 129.76 x 87.48 mm inner loop independently; the 6.00 mm gap between adjacent land outer edges is a hard keepout, not shared seal material.
- Preserve 10.80 mm between adjacent groove outer edges. The per-slot groove
  array retains 8.80 mm to the perimeter groove. These solid shoulders must be
  probed along all four sides of every generated loop.

Perimeter fit on the 12.00 mm A0 land:

- Same 2.40 mm cross-section and 3.20 mm groove width unless vendor review recommends a larger perimeter seal.
- Keep at least 3.0 mm nominal land margin on each side.
- Preserve 48.40 mm X and 54.40 mm Y from the perimeter groove outer edge to the
  lid edge in the active geometry.
- Treat the perimeter loop as a containment/environmental seal; do not design validation around pressurizing the full cassette footprint.

If A2/A4 choose a custom molded rectangular gasket instead of round cord, the substitute must preserve:

- Free height 2.40 mm nominal.
- Compressed height 1.80 mm nominal.
- 20-30% verified squeeze range.
- Groove or pocket geometry with volume expansion room.
- Rounded molded corners and no hand-cut stress risers.
- Same witness-coupon compression and leak evidence.

## Compression Stops

Compression must be set by hard stops and verified by witnesses. Fastener torque is only the method used to bring the lid down to the stops; torque alone is not an acceptable compression-control strategy.

Required stop logic:

| Stop item | Requirement |
| --- | --- |
| Nominal closure contact | Carrier land and hard-stop top faces meet the lid underside at 7.35 mm above carrier top; there is no plate-to-plate gasket gap. The lid groove cavity is 1.80 mm deep. |
| Guard-band verification | Assembly must reject stop stacks that produce less than 1.68 mm or more than 1.92 mm compressed height at any measured witness location. |
| Internal stops | Exactly nine 4.00 mm-diameter stops at the 3 x 3 inter-slot gap intersections, X = -151.76, 0.00, 151.76 mm and Y = -109.48, 0.00, 109.48 mm. These replace per-slot corner stops. |
| Perimeter stops | Existing distributed stops remain 4.00 mm wide and centered in the 5.00 mm seal-to-gutter web. |
| Datum relation | Stop heights must reference the same machined setup as the gasket land/groove where possible. |
| Seal clearance | No internal or perimeter stop may intersect a per-slot or perimeter seal. |
| Witness access | Dedicated witness coupons or witness cavities must be readable without inserting a shim between mating land/stop faces or disturbing the gasket or chip pocket. |

The shared A0 contract places the sixteen per-slot lands, the perimeter land,
and both stop families at 7.35 mm above the carrier top. All meet the lid
underside on the common closure plane matching nominal chip protrusion. The
2.40 mm gasket compresses to the 1.80 mm lid-groove cavity depth. The earlier
3.00/4.00 mm unequal-height scheme, interim shorter-land gap stack, and per-slot
corner stops were geometry defects and are obsolete.

First-article settling criterion: after the initial final-torque pass, hold the
assembly for at least 10 minutes at the test temperature. Recheck the four
corner and center compression witnesses. Repeat the paired final-torque pass
only after every measured witness changes by no more than 0.02 mm over a
5-minute observation interval. If stability is not reached within 30 minutes,
the gasket/closure setup fails and must not proceed to leak testing.

## Witness Shims And Coupons

Witness evidence is required before the cassette is trusted for no-cell liquid testing.

### Assembly Witness Shims

Provide three go/no-go references tied to A0:

| Witness label | Compressed height | Equivalent squeeze |
| --- | ---: | ---: |
| 20% | 1.92 mm | Minimum acceptable squeeze |
| 25% | 1.80 mm | Nominal target |
| 30% | 1.68 mm | Maximum acceptable squeeze |

Use dedicated witness cavities or coupons at the front-left, front-right, rear-left, rear-right, and center-zone locations for both the per-slot field and the perimeter loop. Do not insert these height references between the land/stop faces that must contact the lid underside. If access to all 16 slot loops is impractical, use a mapped sampling plan that includes all four corners, all four rows, all four columns, and at least four interior slots.

### Gasket Compression Coupons

Create separate coupons using the same material, 1.80 mm groove depth, 3.20 mm groove width, land finish, closure-plane stop geometry, and fastener style as the cassette.

Minimum coupon set:

| Coupon | Purpose | Acceptance evidence |
| --- | --- | --- |
| 20/25/30 squeeze ladder | Confirms visual and dimensional witness behavior | Measured compressed height agrees with shim labels. |
| Leak coupon | Isolated small-volume liquid pressure check | No visible dye leak and stable pressure within the defined threshold. |
| Burst coupon | Destructive margin test away from full cassette | Target survival/lower bound recorded; failure pressure/mode only when a separately approved, fully rated ramp-to-failure is safely executed. |
| Gasket reassembly coupon | Repeated closure/reassembly damage screen | Leak test passes at defined cycle counts with inspected gasket surface; this is not a fluid-connector cycle article. |
| Soak coupon | Material and compression-set screen | Post-soak dimensions and visual condition recorded after planned incubation/cleaning exposure. |

Witness coupons must be ticketed/artifacted with material lot, fastener torque-to-stop notes, photos/measurements, and test results. A passed CAD build alone is not gasket validation evidence.

## Surface Finish, Flatness, And Handling Assumptions

Machined metal or suitable engineering plastic is required for first-article seal lands. Printed layer lines are not acceptable on production-intent seal surfaces.

Starting drawing callouts:

| Feature | First-article callout |
| --- | --- |
| Sealing land top/bottom | Ra 0.8 um target and Ra 1.6 um hard maximum for liquid validation; Ra 0.4 um max if gas/vacuum retention is later required. |
| Groove sidewalls | 1.6 um Ra max. |
| Local per-slot land flatness | 0.05 mm target across each seal loop after machining and deburr. |
| Perimeter land flatness | 0.15 mm target around the full perimeter loop and 0.05 mm per 100 mm segment. |
| Burrs | No raised burrs, rolled edges, or anodize buildup that changes squeeze. |
| Machining lay | Avoid continuous radial/cross-groove tool marks that create leak paths across the seal. |
| Coatings | Clear anodize or passivation must be reviewed for seal-land buildup; mask or post-finish lap if needed. |

Cleaning and handling:

- Gasket lands must be inspectable under white light before assembly.
- Do not scrape seal lands with metal tools.
- Replace gaskets after visible cuts, compression cracking, permanent flattening outside supplier limits, contamination, or failed leak evidence.
- Lubricant is not part of the baseline because culture-facing contamination risk is unresolved. If assembly damage requires lubricant, select a documented, biocompatibility-reviewed lubricant and repeat leak/coupon tests.

## Leak, Burst, And Gasket Reassembly Test Logic

All tests below are no-cell, nonhazardous-liquid validation gates. They do not certify sterility, AAV containment, or live-cell readiness.

### Test Order

1. Dimensional inspection of groove depth, groove width, land finish, land/stop height, lid underside, and gasket free height.
2. Dry closure to land/stop contact while reading dedicated witness coupons or cavities.
3. Isolated leak-coupon test at nominal squeeze.
4. Coupon burst test on separate shielded hardware before the cassette is
   hydraulically challenged.
5. Isolated per-slot loop leak tests on the cassette.
6. Perimeter containment leak test without pressurizing the full cassette footprint.
7. Gasket closure/reassembly cycle test.
8. Humid 37 C soak/conditioning followed by repeat leak test.

### Leak Test

Use isolated liquid tests with the smallest practical trapped volume. Do not run a full-envelope pneumatic pressure test on the 600 mm class perimeter loop.

Starting per-loop leak target:

| Parameter | First-article target |
| --- | --- |
| Test medium | DI water with visible dye or equivalent nonhazardous tracer. |
| Isolated gasket-interface qualification pressure | 35 kPa gauge (5 psi) or 1.5x the selected maximum expected cassette fluid-interface pressure, whichever is greater, only for an isolated small-volume gasket loop or representative coupon. |
| Installed-system proof pressure | 1.5x the selected maximum operating pressure, using liquid and remaining below every installed component's qualified proof-pressure limit. A component that cannot support this proof pressure fails selection. |
| Acquisition | After pressure and thermal stabilization, acquire at least 661 seconds. P0 is the mean over t = 0-60 s and P10 is the mean over t = 600-660 s. |
| Pressure-decay acceptance | Guard-banded decay `100 x (P0 - P10) / P0 <= 5%`, with no active pressure makeup and the approved compliance/temperature controls. |
| Visual acceptance | No visible dye in adjacent slot, optical window area, drain gutter, perimeter gutter, or underside witness paper. |
| Documentation | Record loop ID, gasket lot, squeeze witness, start/end pressure, hold time, visible result, and operator. |

Do not weaken either gate to accommodate a selected part. Use a separate
gasket coupon or isolated loop for the 35 kPa/minimum gasket-interface
qualification, and use the installed-system proof pressure for the assembled
chip/tubing/connector path. If any selected component cannot support 1.5x the
maximum operating pressure, change the component or lower the declared
operating pressure before testing.

### Burst Test

Burst validation belongs on coupons or instrumented surrogate loops before the cassette is challenged.

Starting coupon burst target:

- Pressurize a representative coupon loop in liquid to at least 3x the leak-test pressure or 100 kPa gauge (15 psi), whichever is greater.
- Accept the first-article gasket direction only if the coupon reaches the target without leakage, uncontrolled extrusion, hardware damage, or relief/abort excursion at the normal 25% squeeze stop. Record survival as a lower bound of at least the target.
- Continue to failure only under a separately approved method when the fully rated rig ceiling safely exceeds the anticipated failure. If executed, record failure pressure/mode; otherwise do not claim them and never exceed a fixture, instrument, relief, or abort limit merely to obtain failure.

Do not use the full cassette perimeter loop as the first burst article. The clamp load from large-area pressure can dominate the result and damage the lid/carrier before the gasket failure mode is understood.

### Gasket Reassembly Test

Gasket reassembly evidence is required because the cassette is reusable and organ-chip literature treats reversible assembly as a first-class interface risk.

Starting gasket reassembly plan:

| Cycle point | Action |
| ---: | --- |
| 1 | Leak test, inspect gasket and lands. |
| 5 | Leak test, inspect for cuts, flattening, twist, and debris. |
| 10 | Leak test and dimensional spot-check of compressed witness marks. |
| 25 | Leak test, inspect, and decide whether 100-cycle durability is needed before live-cell work. |

The 25-cycle first-article gate is a minimum. Escalate to 100 cycles if the cassette workflow requires frequent chip swaps, if the selected material has uncertain compression-set behavior, or if supplier data is weak.

## Resolved Decisions And Escalations

| Item | A3 disposition | Owner for next action |
| --- | --- | --- |
| First gasket form | Resolve to replaceable continuous axial face seals, 2.40 mm nominal round cord/O-ring baseline. | A2/A4 to implement in drawings; vendor to review. |
| First material baseline | Resolve to quote platinum-cured silicone first, high-purity EPDM alternate. | A4/vendor; validation coupons compare both if budget allows. |
| Compression target | Keep A0 25% nominal with 20-30% allowed band. | A2 hard stops and A4 tolerance stack. |
| Groove dimensions | Locked nominal lid cavity: 1.80 mm depth, 3.20 mm width, 0.20 mm entry radius for 2.40 mm cross-section. | A4/vendor to confirm tolerance, fill, and corner radius before release drawing. |
| Stop strategy | Resolve to nine 4.00 mm-diameter inter-slot stops plus 4.00 mm-wide perimeter web stops, all at 7.35 mm; torque alone is not acceptable. | A2 lid/clamp and A4 DFM. |
| Common land elevation | Resolved by the shared A0 contract: both seal families and all stops are 7.35 mm above carrier top and meet the lid underside on the closure plane. The nominal compressed gasket occupies the 1.80 mm lid groove. | Integrator/A2/A4. |
| Surface finish | Resolve Ra 0.8 um liquid seal-land target and Ra 1.6 um hard maximum; Ra 0.4 um max if a gas/vacuum claim is added. | A4 drawing package/vendor. |
| Leak-test pressure | Resolve two fail-closed liquid gates: isolated gasket qualification at max(35 kPa gauge, 1.5x maximum operating pressure), and installed-system proof at 1.5x maximum operating pressure below every installed component's qualified proof limit. | Validation agent to fixture and characterize compliance. |
| Burst validation | Resolve to coupon/surrogate burst first; no full-cassette perimeter burst before structural review. | Validation agent/A2. |
| Gasket reassembly durability | Resolve 25-cycle first gate, escalate to 100 cycles when workflow or material uncertainty requires it. | Validation agent/integrator. |
| Wetted gasket use | Escalate: no gasket is approved as culture-fluid/AAV-contacting until material absorption, extractables, and cleaning compatibility are reviewed. | Integrator/fluid-path/biology owner. |
| Lubrication | Escalate: baseline is dry assembly. Any lubricant requires compatibility review and repeated coupon tests. | A4/vendor/validation. |

## Targeted Exa Research Pass

The A3 research pass was intentionally limited to face seals, elastomer selection, organ-chip gasket interfaces, and leak/burst validation.

| Source | Finding used by A3 |
| --- | --- |
| Apple Rubber, Seal Design Guide, https://www.applerubber.com/src/pdf/seal-design-guide.pdf | Seal design must be application-verified; material, gland, environment, and failure mode cannot be inferred from nominal gasket size alone. |
| Sealing Devices, O-ring face seal guide, https://sealingdevices.com/blog/o-ring-face-seal-design-guide/ | Axial face seals depend on groove depth/width, plate gap, surface quality, flatness, tolerance stack, deburr/radius, torque pattern, and early pressure/media/temperature validation. |
| Ace Seal static axial gland guide, https://www.aceseal.com/gland-design-static-axial-application | Static axial liquid-face-seal guidance informed the cavity sizing and 3.20 mm width; A0 fixes the nominal depth at the exact 1.80 mm compressed height. Liquid land finish target is 32 microinch / 0.8 um Ra and gas/vacuum is finer. |
| KEF America medical elastomer tradeoff note, https://www.kef-america.com/material-tradeoffs-silicone-vs-fluoroelastomers-vs-epdm-for-medical-devices/ | Silicone, EPDM, and fluoroelastomers have different biocompatibility, chemical, permeability, and compression-force tradeoffs; compound-specific data matters. |
| James Walker Elast-O-Pure EP75, https://www.jameswalker.biz/our-solutions/our-products/elastomers/materials-for-biopharmaceutical-applications/elast-o-pure-ep75 | High-purity USP Class VI EPDM-class materials exist for biopharmaceutical sealing and are credible alternates to silicone. |
| Minahan et al., modular reusable perfusion-ready MPS cassette, https://pmc.ncbi.nlm.nih.gov/articles/PMC12914553/ | Reusable cassette hardware with elastomeric inserts and clamping can support reversible leak-tight organ-chip assembly while preserving imaging access. |
| Sun et al., reusable standardized universal interface module, https://www.mdpi.com/2072-666X/10/12/849 | Reusable organ-chip interfaces emphasize standardized alignment, reversible clamping, and leakage-free assembly. |
| Integrated micro-gasket multi-organ chip connections, https://www.mdpi.com/2072-666X/16/11/1251 | TPE/SEBS integrated microgaskets are relevant for reversible organ-chip connections; burst, durability, repeated detachment/reconnection, and incubation exposure are appropriate validation categories. |
| Gong et al., high-density reversible microfluidic interconnects, https://pmc.ncbi.nlm.nih.gov/articles/PMC5811381/ | Microgasket validation can include pressure monitoring, visible liquid leak observation, high-pressure margin testing, and repeated reconnection cycles; reported systems demonstrate 50 psi and 100 reconnections for their specific microgasket architecture, not as direct LaminarForge acceptance limits. |

## Manufacturer Drawing Notes To Carry Forward

Add these notes to the A4 drawing package when the gasket geometry is promoted from spec to drawings:

- Gasket glands are controlled-compression axial face seals; do not substitute adhesive gasket or RTV without engineering approval.
- Seal surfaces must be free of burrs, tool marks crossing the seal path, coating buildup, and printed layer texture.
- Supplier must confirm gasket compound, durometer, dimensional tolerance, compression set, and cleaning/incubation compatibility.
- Vendor should review groove fill, squeeze stack, corner radii, and splice/mold strategy before machining.
- Compression stops and witness coupons are part of the deliverable, not optional inspection extras.

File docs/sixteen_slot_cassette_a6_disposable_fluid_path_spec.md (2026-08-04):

# 16-Slot Cassette A6 Disposable Fluid-Path Spec

Ticket: T-253E1123

This A6 spec defines the disposable fluid-path architecture for the first physical LaminarForge 16-slot AAV cassette build. It is subordinate to `docs/sixteen_slot_cassette_a0_interface_spec.md` and must mate with the A1 carrier, A2 lid/clamp, A3 gasket, A4 DFM, and A5 integrated mechanical-stack decisions.

This is not a biological protocol, sterile-barrier validation, AAV containment claim, live-cell release criterion, or final vendor drawing. It defines the first-article tubing harness, routing, bought connector assumptions, prime path, waste path, bubble visibility, and validation handoffs.

## A6 Baseline

| Item | A6 requirement |
| --- | --- |
| First-build format | 16 slots in a 4 x 4 cassette. |
| Experimental unit | One cassette equals one AAV capsid/promoter/payload/dose/timing/media condition. |
| Slot role | Slots are cell-type and technical readouts under the same exposure, not separate AAV candidates. |
| Wetted path | Disposable commercial tubing, connectors, reservoirs, filters, and pump-contact tubing. |
| Reusable hardware role | Carrier, lid, dock, bulkhead, and structural cassette parts remain dry fixtures. |
| First-article flow mode | Pressure-limited single-pass feed from a common condition reservoir through matched branches to sealed waste. |
| Recirculation | Deferred. Do not recirculate AAV/media in the first article until recovery, sterility, and carryover evidence justify it. |
| Mixed-AAV routing | Blocked. Do not route multiple AAV candidates through one cassette or shared waste/manifold. |
| Incubation control | Deferred to module work. A6 only reserves gas/vent/service interfaces. |
| Active carrier | 699.04 x 541.92 x 24.00 mm base body; 699.04 x 541.92 x 31.35 mm true overall. |
| Clamp keepout | 7.35 mm land/stop/lid closure plane; nine internal and distributed perimeter stops clear every seal; 16 fasteners and 3.30 mm carrier pilots remain outside the gutter at X = +/-332.52 mm or Y = +/-247.96 mm. |
| Dock registration | Carrier bottom seats directly on datum A; rear/left rail inner faces and front lip contact nominal carrier edges. |
| Service bulkhead base body / true overall | 789.04 x 34.00 x 76.00 mm / 789.04 x 60.00 x 76.00 mm. |
| Sensor/backplane cut | Center X = 320.00 mm, center Z = 18.00 mm; preserve clearance from W4. |
| Carrier routing relief | Left/right service relief bands are 7.00 mm high above carrier top and remain below the 7.35 mm lid underside closure plane. |

## System Boundary

A6 owns:

- Disposable tubing harness architecture.
- Bulkhead port assignment assumptions.
- Reservoir, pump, filter, connector, and waste interfaces as bought-component placeholders.
- Prime, purge, leak-test, waste, and bubble-visible routes.
- Dead-volume accounting and dose-recovery evidence requirements.
- Connector topology and run-record fields needed to prevent wrong-condition assembly.

A6 does not own:

- Chip culture protocol, AAV dose selection, or cell-type media formulation.
- Final sterile validation, IBC release, or live-cell readiness.
- Pump-controller hardware selection beyond interface assumptions.
- Final vendor drawings for the carrier/lid/gasket stack.
- Final no-cell validation fixture design, except for acceptance data A7 must collect.

## Target Architecture

The first article uses one disposable harness per cassette run.

Fluid path:

1. Common condition reservoir or bag.
2. Optional inline sterile filter only if the selected media/AAV workflow can tolerate the filter and recovery loss.
3. Pump or pressure-control interface with pressure limit.
4. Upstream bubble/debubble section with clear visual window.
5. Common supply trunk.
6. Four row branches with equalized routing.
7. Four slot branches per row, one inlet pigtail per chip.
8. One outlet pigtail per chip to a matched row waste branch.
9. Common sealed waste bag or waste bottle with anti-backflow protection.

The first article should be single-pass, not recirculating. Recirculation saves reagent, but it also couples all chips through a shared return volume, increases contamination consequence, and complicates dose-recovery/carryover analysis. A6 therefore treats recirculation as a future controlled module after no-cell flow, bubble, and recovery data exist.

## Condition Semantics

All wetted parts in one cassette harness are assigned to one and only one condition:

- Cassette ID.
- Harness ID.
- AAV condition ID.
- Capsid ID.
- Promoter ID.
- Payload ID.
- Dose/MOI.
- Media recipe.
- Pump/flow recipe.
- Slot map revision.
- Connector topology revision.

If a future experiment needs different media recipes for different cell types, that requirement conflicts with the first A6 shared-condition harness. The acceptable first-article options are to choose a common assay/exposure medium for the cassette window, run separate cassettes, or open a new isolated-lane design ticket. Do not silently use the 16 slots as separate media/AAV lanes.

## Bulkhead Port Assignment

The shared A0 contract implements a dry service bulkhead placeholder with four gas ports, seven media ports, five waste ports, a sensor/backplane cut centered at X = 320.00 mm, and twelve tubing strain-relief comb teeth. Its 789.04 x 34.00 x 76.00 mm base body has 789.04 x 60.00 x 76.00 mm true overall bounds after the added label/strain-relief features. A6 assigns the following first-article logical roles without freezing final connector geometry.

### Gas/Pressure Ports

| Port | Current CAD basis | A6 logical role | First-article note |
| --- | --- | --- | --- |
| G0 | 8.00 mm diameter cut at X = -240.00, Z = 18.00 | Sterile reservoir vent or bag headspace vent path | Use bought sterile vent/filter if open-to-atmosphere venting is needed. |
| G1 | 8.00 mm diameter cut at X = -210.00, Z = 18.00 | Pressure controller or regulated gas input | Pressure limit must be below the weakest validated component. |
| G2 | 8.00 mm diameter cut at X = -180.00, Z = 18.00 | Relief/exhaust or pressure-test vent | Route to safe exhaust or waste capture during no-cell tests. |
| G3 | 8.00 mm diameter cut at X = -150.00, Z = 18.00 | Reserved gas sample / future CO2 module interface | Do not depend on this for first-article incubation control. |

### Media/Condition Ports

| Port | Current CAD basis | A6 logical role | First-article note |
| --- | --- | --- | --- |
| M0 | 6.40 mm diameter cut at X = -78.00 | Common condition feed inlet | Main cassette feed for media/AAV condition. |
| M1 | 6.40 mm diameter cut at X = -52.00 | Media/rinse feed inlet | No-cell/media-only validation or preflush; not a second AAV candidate. |
| M2 | 6.40 mm diameter cut at X = -26.00 | Prime/debubble bypass inlet | Allows harness prime to waste before exposing chip branches. |
| M3 | 6.40 mm diameter cut at X = 0.00 | Pressure/leak-test inlet | Used by A7 validation fixture and dye tests. |
| M4 | 6.40 mm diameter cut at X = 26.00 | Sample/QC loop inlet | Optional closed sampling path; not required for first flow test. |
| M5 | 6.40 mm diameter cut at X = 52.00 | Inline sensor/cartridge service inlet | Reserved for pH/DO/conductivity module work. |
| M6 | 6.40 mm diameter cut at X = 78.00 | Spare / vendor-selected connector alternate | Keep capped in first article if unused. |

### Waste/Return Ports

| Port | Current CAD basis | A6 logical role | First-article note |
| --- | --- | --- | --- |
| W0 | 6.40 mm diameter cut at X = 150.00 | Common chip outlet waste | Main sealed waste path. |
| W1 | 6.40 mm diameter cut at X = 176.00 | Prime/debubble purge waste | Used until upstream and branch bubble windows are clear. |
| W2 | 6.40 mm diameter cut at X = 202.00 | Sample/QC waste | Optional sample-loop waste; keep capped if unused. |
| W3 | 6.40 mm diameter cut at X = 228.00 | Leak-test/dye-test waste | A7 fixture can isolate this path from biological waste. |
| W4 | 6.40 mm diameter cut at X = 254.00 | Relief/overflow/emergency waste | Must include backflow/siphon control if connected. |

The placeholder diameters are not final connector drawings. A4 remains correct: vendor drawings must dimension bought connector panel geometry, not generic holes.

## Tubing Harness Layout

Use a preassembled, labeled disposable harness with a repeatable physical topology.

Required harness zones:

| Zone | Function | A6 requirement |
| --- | --- | --- |
| Reservoir lead | Links bag/reservoir to pump interface | Short, labeled, replaceable, compatible with selected sterile connector or tube welding method. |
| Pump segment | Interfaces with syringe, peristaltic, or pressure controller | Selected by pump agent; must be separately calibrated and replaceable. |
| Upstream bubble window | Visible high point before the cassette branches | Clear tubing or clear inline chamber; must be inspectable when docked. |
| Common supply trunk | One condition feed to all 16 branches | No branch may receive a different AAV candidate. |
| Row branches | Four row feeds | Route as matched lengths where practical; label R1-R4. |
| Slot inlet pigtails | Sixteen chip inlet connections | Label S01-S16; length and bend radius recorded. |
| Slot outlet pigtails | Sixteen chip outlet connections | Route to row waste branches; no open-drain exposure. |
| Waste trunk | Common outlet to sealed waste | Include anti-backflow/siphon control and waste identity label. |
| Prime bypass | Lets pump prime to waste before opening chip branches | Must be visible and pressure-limited. |

Use tubing combs, clips, or harness trays so assembly does not rely on memory. The twelve A5 bulkhead comb teeth are strain-relief placeholders, not a complete topology-control system; the build package must add a physical route map or keyed tray for all chip pigtails.

## Routing Keepouts

Tubing, connectors, clips, filters, and labels must stay out of:

- All 16 lid view openings.
- Carrier optical through-windows.
- Gasket lands, lid grooves, the nine 4.00 mm-diameter internal hard stops, the
  4.00 mm-wide perimeter web stops, and dedicated witness access. No route may
  cross or load a seal or stop.
- Datum bosses, the direct datum-A dock support, rear/left rail inner faces, and
  front retention lip where they contact the nominal carrier edges.
- Carrier global condition ID land and slot-1 orientation marker.
- All global and per-slot label lands, which the shared A0 contract places outside the leak gutter.
- Dock logger pockets unless assigned by the sensor/module agent.
- Robot lift lands and carrier handling lands.
- Leak gutter and visible drain/sump inspection paths.

Preferred routing is from the rear service bulkhead into the 7.00 mm-high side service relief bands, then into controlled row/slot pigtails. The reliefs remain below the 7.35 mm closure plane and cannot be used to prop the lid open. Any tube crossing the top of a slot must be rejected unless the integrator explicitly updates the imaging strategy.

## Bought Connector Strategy

A6 resolves the first article to bought sterile/aseptic connection technology, not custom machined sterile ports.

Acceptable first-article options:

| Option | Use | Requirement |
| --- | --- | --- |
| Preassembled single-use harness | Best early path if a vendor can provide sterile or clean disposable sets | Harness is released as a kit with lot, route map, caps, and leak-test evidence. |
| Sterile tube welding | Useful for compatible PVC/TPE/C-Flex-style tubing | Weld cycle metadata, tubing material, OD/ID, and weld coupons must be recorded. |
| Single-use aseptic connectors | Useful for reservoir and module handoffs | Connector family, termination size, pressure rating, temperature rating, sterilization mode, and extractables/compatibility data must be captured. |
| Non-sterile low-dead-volume microfluidic connectors for no-cell tests only | Useful for early water/dye validation | Must be clearly blocked from live-cell/AAV use until aseptic and material compatibility evidence exists. |

Do not custom-machine sterile connector geometry into the aluminum carrier, lid, dock, or service bulkhead for first article. Those parts can hold, key, strain-relieve, or label bought components; they cannot become the validated sterile boundary by assertion.

## Tubing Material Direction

No final AAV-contact tubing material is frozen by A6. The first quote/test set should compare a weldable TPE/PVC-compatible route against a silicone/peristaltic-pump route if budget allows.

Starting material assumptions:

- Prefer weldable TPE/C-Flex-style tubing where sterile tube welding is part of the selected workflow.
- Use silicone or platinum-cured silicone pump tubing only where pump mechanics or connector availability require it.
- Minimize total wetted surface area and dead legs because AAV, proteins, growth factors, and small additives may adsorb to tubing/filter/connector surfaces.
- Treat any inline filter, debubbler membrane, or connector seal as a recovery-risk item until dye and biological surrogate recovery tests pass.
- Record tubing OD, ID, wall thickness, lot, supplier, sterilization state, and expiration/retest status.

## Prime And Debubble Path

Priming must be possible before chips are exposed.

Required sequence for no-cell validation:

1. Connect reservoir, pump interface, bubble window, prime bypass, and waste.
2. Prime common upstream line to W1 until visible bubbles clear.
3. Prime row branches one row at a time to waste or collection wells.
4. Prime each slot pigtail through a no-cell surrogate chip or restriction coupon.
5. Verify no visible bubble remains at chip inlet, row branch high point, or outlet.
6. Record prime volume, time, pressure, flow setting, and waste recovery.
7. Only after priming evidence passes may the harness be used for media-only or live-cell planning.

The harness must include bubble-visible sections at:

- Upstream of the cassette branch split.
- Each row branch high point or row manifold outlet.
- At least one outlet witness path before common waste.
- Any vertical high point introduced by the dock or module.

If bubbles cannot be seen while the cassette is docked, the design fails A6.

## Waste And Backflow Control

Waste is a closed or semi-closed disposable path, not an open drain.

Required waste controls:

- Main waste route W0 to sealed waste bag/bottle.
- Separate prime/purge waste W1 during setup.
- Dye/leak-test waste W3 separable from biological waste assumptions.
- Anti-backflow or anti-siphon strategy before any live-cell plan.
- Waste bag/bottle identity label linked to cassette ID and condition ID.
- Secondary containment or leak tray under waste handoff.
- No shared waste container between different AAV candidates unless carryover/containment is separately validated.

Waste backflow/siphon testing is handed to A7 but must be physically possible from the A6 harness.

## Physical Hold-Up And Dose-Recovery Model

Every disposable harness revision needs a volume ledger before biological use.

Record calculated and measured volume for:

- Reservoir outlet to pump inlet.
- Pump segment.
- Pump outlet to upstream bubble window.
- Bubble/debubble element.
- Common supply trunk.
- Each row branch.
- Each slot inlet pigtail.
- Each chip/surrogate internal path.
- Each slot outlet pigtail.
- Row waste branches.
- Common waste trunk.
- Prime bypass.
- Sample/QC loop if present.

Initial engineering target: the one-sided upper bound on physical retained/
hold-up volume, including recovery and measurement uncertainty, must be less
than one chip dose or 10% of the formulated cassette condition volume,
whichever is more conservative. Tracer mass non-closure is reported separately
and cannot alone be relabeled hydraulic dead volume because adsorption and
analytical loss are confounded. Missing or failed recovery evidence blocks
expensive vector work; operator or integrator judgment cannot waive this gate.

## Flow Balance And Pressure Limits

A6 does not freeze a pump. It freezes what the pump/service module must prove.

Starting no-cell targets before live-cell planning:

| Metric | Initial target |
| --- | --- |
| Row flow balance | Row collected-volume CV <= 10% during no-cell multiplex flow. |
| Slot flow balance | Slot collected-volume CV <=10% for the characterized nominal no-cell surrogate set. Actual-chip limits require a new evidence-backed gate after chip restriction data exists. |
| Pressure drift | Stable within +/-5% after thermal and compliance stabilization. |
| Pressure ceiling | Routine operation <=50% of the lowest credible temperature-derated failure/burst/connector limit after approved engineering margin, and no higher than any supplier-rated working pressure. The 1.5x installed proof checkpoint and a lone coupon result are not operating ratings. |
| Installed-system leak test | No visible leak and guard-banded decay `100 x (P0 - P10) / P0 <= 5%` at 1.5x selected maximum operating pressure, using liquid, no active pressure makeup, at least 661 s acquisition, P0 mean over t = 0-60 s, and P10 mean over t = 600-660 s. Remain below every installed component's qualified proof-pressure limit; a selected component that cannot support it fails selection. |
| Isolated gasket qualification | A separate coupon or isolated gasket loop passes A3's max(35 kPa gauge, 1.5x maximum operating pressure) liquid gate. |
| Bubble challenge | Introduced upstream bubble clears to waste without reaching a chip inlet witness during validated prime/debubble mode. Bubble volume and maximum clearing volume/time must be frozen in A7 before this gate is executable. |
| Recovery | Dye or surrogate recovery reconciles input/output/waste within the A7-defined mass-balance tolerance. |

A7 owns the final validation fixture and acceptance thresholds. A6 requires the physical ports and harness topology to support these measurements.

## Connector Topology And Run Record

Wrong-port assembly is a first-order failure mode.

The build package must include:

- Harness revision ID.
- Port map from G/M/W bulkhead positions to connector labels.
- S01-S16 pigtail labels.
- R1-R4 branch labels.
- Reservoir, waste, filter, pump segment, connector, and tubing lot IDs.
- Cap/plug status for unused ports.
- Pre-run scan or photo evidence of the assembled topology.
- Pass/fail status for prime, leak, bubble, and volume-balance checks.

Any physical connector pair that can be swapped must be keyed, color coded, scan checked, or physically segregated. Labels alone are not enough for repeated work.

## Research Basis

The A6 research pass was limited to organ-chip fluid interfaces, world-to-chip connector burden, parallelized fluidic boards, and bought aseptic connection technology.

| Source | Finding used by A6 |
| --- | --- |
| Minahan et al., modular reusable perfusion-ready MPS cassette, https://pmc.ncbi.nlm.nih.gov/articles/PMC12914553/ | Reusable cassette hardware can clamp disposable/interchangeable fluidic layers while preserving imaging and separating reusable structure from consumable interfaces. |
| TapeTech microfluidic connectors, https://pubs.rsc.org/ak/content/articlehtml/2025/lc/d4lc00970c | World-to-chip connections are a major setup burden; simplified connectors can reduce pressure surges, improve priming, improve multiplexing, and reduce setup errors. |
| Pressure-driven perfusion system for organs-on-chips, https://pmc.ncbi.nlm.nih.gov/articles/PMC9416133/ | Pressure-driven perfusion and fluidic circuit board strategies can multiplex and recirculate OoC media, but throughput requires controlled routing and software/fixture support. |
| Vollertsen et al., modular FCB for parallelized cell culture, https://preview-www.nature.com/articles/s41378-020-00216-z | Standardized fluidic circuit boards can operate multiple microfluidic building blocks with parallelized liquid dosing and controlled interfaces. |
| Sterile fluid transfer for cell therapy manufacturing, https://pmc.ncbi.nlm.nih.gov/articles/PMC8931546/ | Closed sterile transfer commonly relies on single-use sterile connectors and tube welders; frequent small-volume transfers require device and workflow selection, not improvised open handling. |
| CPC AseptiQuik C product information, https://www.cpc-bio.com/products-overview/connectors/technologies/aseptic-sterile-connectors/aseptiquik-c | Bought aseptic connectors include pressure, temperature, sterilization, material, and termination constraints; supplier warns users must test suitability in their application. |
| Sartorius Biowelder S product information, https://www.sartorius.com/en/products/fluid-management/aseptic-connectors/sterile-connection-device | Sterile tube welding is a bought-device workflow for compatible PVC/TPE tubing and can provide weld metadata; tubing material compatibility is central. |
| STARTER modular OoC platform, https://pubs.rsc.org/en/content/articlehtml/2026/lc/d5lc00756a | Modular open OoC platforms use standardized footprints and swappable pumping/sensing/OoC modules; LaminarForge should preserve service interfaces for later modules. |

## A0 Interface Decisions Implemented By A6

| Interface decision | A6 resolution |
| --- | --- |
| Connector family | Do not freeze one final connector family. Use bought aseptic connectors or sterile tube welding for live-use planning; use low-dead-volume microfluidic connectors only for no-cell tests until validated. |
| Tube OD/ID | Not frozen. Record OD/ID and quote weldable TPE/C-Flex-style and silicone/peristaltic options. |
| Bend radius | Must follow supplier minimum bend radius and be preserved by combs/trays; no kinked pigtails or memory-dependent routing. |
| Port assignment | Assign G0-G3, M0-M6, and W0-W4 logical roles as above while preserving placeholder CAD geometry. |
| Valve/pump interface | Pump not frozen; interface must support pressure-limited single-pass flow, prime-to-waste, branch isolation/testing, and flow/pressure logging. |
| Sterile connection method | Bought sterile connectors or tube welding only; no custom machined sterile boundary in structural hardware. |
| Bubble visibility | Required at upstream split, row branches, outlet/waste witness, and any vertical high point. |
| Dead-volume measurability | Required volume ledger and dye/surrogate recovery before AAV work. |

## A0 Decisions Escalated

| Decision | Escalation path |
| --- | --- |
| Final connector SKU and panel geometry | A8 build package/vendor RFQ after tubing/pump selection. |
| Final tubing material for AAV contact | Biology/material compatibility review plus recovery testing. |
| Pump type and control profile | Pump/service-module owner. |
| Branch equalization geometry and actual pressure-flow model | A7 validation fixture with no-cell restriction coupons. |
| Sterility/aseptic process claim | Media-fill and facility/IBC workflow; not CAD alone. |
| Waste containment and AAV decontamination SOP | Safety/IBC and validation owner. |
| Recirculation | Future module after single-pass evidence. |

## CAD Handoff Notes

The STL and true B-rep STEP draft generators now consume the shared machine-readable A0 geometry contract. The geometric update corrected the earlier carrier/seal/gutter conflicts, moved the 16 clamp fasteners and their 3.30 mm carrier pilots outside the gutter, and locked the service relief below closure while preserving the A6 role map exactly: G0-G3, M0-M6, and W0-W4 retain the assignments above. The service bulkhead remains a placeholder for bought connector cutouts and strain relief. Future CAD changes should add:

- Keyed connector nests based on selected connector datasheets.
- A physical harness route map or tray.
- Bubble-window keepouts visible when docked.
- Cap/plug parks for unused ports.
- Waste/prime segregation labels.
- Gauge-chip/no-cell validation fixture interfaces for pressure, dye, and gravimetric collection.

Any future CAD change must preserve A0 slot count, one-condition semantics, dry structural hardware policy, imaging keepouts, gasket compression access, and service-bulkhead traceability unless the cassette integrator revises the A0 contract.

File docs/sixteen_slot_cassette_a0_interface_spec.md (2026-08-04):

# 16-Slot Cassette A0 Interface Control Spec

Architecture status: active first-build interface contract. The 16-slot, 4 x 4
cassette is the first physical LaminarForge AAV cassette architecture.
`docs/standard_footprint_aav_condition_module_a0.md` is a supplemental compact
module and local-coupon study; it does not supersede this contract or satisfy a
16-slot first-article gate.

This is the shared interface contract for the first physical LaminarForge AAV cassette build. Downstream carrier, lid/clamp, gasket, DFM, fluid-path, validation-fixture, and build-package agents must design against this spec unless the cassette integrator updates it.

This is not a production drawing, biological protocol, sterile-barrier claim, or live-cell release criterion. It is the geometry and interface baseline for the first article.

## Locked Decisions

- First build format: 16 slots in a 4 x 4 grid.
- Experimental unit: one cassette equals one AAV capsid/promoter/payload/dose/timing/media condition.
- Slot role: the 16 positions are cell-type and technical readouts under the same exposure, not separate AAV candidates.
- Active CAD baseline: `sixteen_slot_cassette_incubator_first_article`.
- Older 20-chip / 4 x 5 CAD: reference and future scale direction only until the 16-slot cassette is validated.
- Wetted-path policy: first article uses disposable commercial tubing/connectors. Structural cassette parts are dry fixtures unless separately validated.
- Incubation policy: do not solve CO2 incubation in this package. Reserve dock/module interfaces so a cassette-level controlled module can be added later.
- Precision policy: local coupons and compact-module studies may retire chip-fit,
  gasket, connector, and imaging risks before full-carrier fabrication, but they
  may not change the slot map, datums, condition semantics, or active first-build
  package without an explicit A0 revision.

## A0 Revision Basis

The current contract replaces the original 7.00 mm-gutter fit-check geometry.
That draft could not serve as an interface contract: its raised land opening was
smaller than the chip, adjacent gasket loops overlapped, the closure plane sat
below the nominal chip top, slot/global labels intersected functional zones,
fastener retainers crossed the perimeter seal, the gutter crossed the seal land,
and the STEP carrier omitted the drain. Those geometries are rejected and must
not be restored as compatibility variants.

`src/sixteen_slot_cassette_a0.rs` now fails closed on the controlling
non-intersection and parity checks. The full-size STL and STEP generators import
the same contract rather than carrying separate interface constants.

## Coordinate System

All dimensions are millimeters.

- X/Y origin: center of the 16-slot cassette array, coincident with the carrier
  and dock X/Y centerlines.
- X axis: chip long edge / cassette columns.
- Y axis: chip short edge / cassette rows.
- Assembly Z origin: dock base-body midplane. Z is positive upward. The dock
  support/datum-A plane is therefore Z = +11.00, not Z = 0.
- Individual part files use part-local Z = 0 at the base-body midplane. The
  stackup reference applies the transforms below; do not mix a part-local Z
  coordinate with the assembly frame without that transform.
- Slot numbering: row-major from front/negative Y to rear/positive Y, and left/negative X to right/positive X.

| Part/reference | Part-local base-body span | Assembly transform / controlling face |
| --- | --- | --- |
| Dock | Z = -11.00 to +11.00 | No translation; top support/datum A = +11.00. |
| Carrier | Z = -12.00 to +12.00 | Translate +23.00; bottom/datum A = +11.00, base top = +35.00, closure plane = +42.35. |
| Lid | Z = -5.00 to +5.00 before retained features | Translate +47.35; underside sealing face = +42.35. |
| Window placeholder | Z = -1.50 to +1.50 before retained features | Translate +55.85 in the stackup reference. |
| Service bulkhead | Part-local block centered at Z = 0 | Translate +49.00; bottom = +11.00. |

| Slot row | Slot numbers |
| --- | --- |
| Row 1, Y = -164.22 | 1, 2, 3, 4 |
| Row 2, Y = -54.74 | 5, 6, 7, 8 |
| Row 3, Y = 54.74 | 9, 10, 11, 12 |
| Row 4, Y = 164.22 | 13, 14, 15, 16 |

## Core Dimensions

These values are sourced from the machine-readable contract in
`src/sixteen_slot_cassette_a0.rs`. The STL and STEP generators both import that
contract. “Base body” describes the starting plate/block; “overall” includes
additive rails, lands, retainers, shelves, or witness features.

| Interface | Value |
| --- | ---: |
| Rev C chip length, X | 127.76 |
| Rev C chip width, Y | 85.48 |
| Rev C chip total height | 14.35 |
| Cassette columns x rows | 4 x 4 |
| Slot count | 16 |
| Slot gutter X | 24.00 |
| Slot gutter Y | 24.00 |
| Slot pitch X | 151.76 |
| Slot pitch Y | 109.48 |
| Slot array X | 583.04 |
| Slot array Y | 413.92 |
| Carrier margin X | 58.00 per side |
| Carrier margin Y | 64.00 per side |
| Carrier base body | 699.04 x 541.92 x 24.00 |
| Carrier generated overall | 699.04 x 541.92 x 31.35 |
| Lid/clamp base body | 717.04 x 559.92 x 10.00 |
| Lid/clamp generated overall | 717.04 x 559.92 x 11.60 |
| Lid underside seal skin / upper frame | 4.00 continuous / 6.00 relieved |
| Lid chip-top relief per slot | 130.16 x 87.88 x 0.50 deep |
| Window placeholder base panel | 667.04 x 489.92 x 3.00 |
| Window placeholder generated overall | 667.04 x 489.92 x 4.80 |
| Dock plate base body | 869.04 x 691.92 x 22.00 |
| Dock plate generated overall | 869.04 x 691.92 x 40.00 |
| Service bulkhead base body | 789.04 x 34.00 x 76.00 |
| Service bulkhead generated overall | 789.04 x 60.00 x 76.00 |

## Exa Research Anchors

These references were checked during A0 to keep the interface spec aligned with current organ-chip and seal/fluid-interface practice.

| Source | Useful finding | A0 implication |
| --- | --- | --- |
| Minahan et al., modular reusable perfusion-ready MPS cassette, PMC12914553 | Uses a reusable acrylic cassette and compressible elastomeric inserts; clamping forms reversible leak-tight channels and preserves imaging access. | Keep LaminarForge's carrier reusable and structural, with disposable or separately validated culture/fluid-contact layers. Treat screw/clamp compression and imaging access as load-bearing requirements. |
| Sun et al., reusable standardized universal interface module, Micromachines 2019 | Reusable interface module supports plug-and-play organ-chip coupling; clamping-based approaches are explicitly evaluated for leakage-free reversible assembly. | Make datums, reversible clamping, and repeated assembly/disassembly part of the interface contract, not later accessories. |
| Vollertsen et al., fluidic circuit board for parallelized cell culture, PMC8433198 | A fluidic circuit board can operate multiple microfluidic building blocks with standardized interfaces and high parallelization. | Treat cassette ports and bulkhead zones as a frozen interface board. Downstream agents should avoid ad hoc tubing layouts that cannot be reproduced. |
| STARTER open modular organ-chip platform, PMC12834090 | Open modular platform uses swappable pump, sensor, and organ-chip modules within standard footprint logic and emphasizes interoperability. | Preserve module/dock interfaces and sensor zones even though active incubation control is deferred. |
| Static O-ring face seal guidance, allorings.com | Face seals require selected gland dimensions, compression, corner radii, and surface finish; typical recommendations call out smoother surfaces for gas sealing than liquids. | A0 fixes the 2.40 mm cross-section, 1.80 x 3.20 mm lid groove, and 25% nominal squeeze; the gasket supplier, compound, tolerances, finish, and groove-fill evidence still require vendor review. |
| TapeTech microfluidic connectors, PMC11795533 | World-to-chip connections are a major source of setup burden, pressure surges, priming issues, and errors; scalable connector strategy matters. | A6 must design prime/waste/bubble-visible routing and connector topology as a first-class interface, not loose tubing afterthoughts. |
| Sterile fluid transfer for cell therapy manufacturing, PMC8931546 | Closed systems commonly rely on sterile connectors or tube welders; sterile transfer has device, training, tubing material, and connection-frequency constraints. | First article should assume bought sterile connectors/tubing and document connector compatibility instead of custom sterile claims. |
| Integrated micro-gasket multi-organ chip connection, Micromachines 2025 | Thermoplastic elastomer gasket connections are tested for burst pressure, durability, repeated detachment/reconnection, and incubation exposure. | Gasket witness coupons and no-cell leak/burst/reconnection tests should be part of validation before live-cell or AAV work. |

## Slot Centers

| Slot | X | Y |
| ---: | ---: | ---: |
| 1 | -227.64 | -164.22 |
| 2 | -75.88 | -164.22 |
| 3 | 75.88 | -164.22 |
| 4 | 227.64 | -164.22 |
| 5 | -227.64 | -54.74 |
| 6 | -75.88 | -54.74 |
| 7 | 75.88 | -54.74 |
| 8 | 227.64 | -54.74 |
| 9 | -227.64 | 54.74 |
| 10 | -75.88 | 54.74 |
| 11 | 75.88 | 54.74 |
| 12 | 227.64 | 54.74 |
| 13 | -227.64 | 164.22 |
| 14 | -75.88 | 164.22 |
| 15 | 75.88 | 164.22 |
| 16 | 227.64 | 164.22 |

## Chip Pocket Interface

Current CAD baseline:

- Pocket size: Rev C chip length/width plus 1.20 mm clearance per side.
- Pocket X: 130.16.
- Pocket Y: 87.88.
- Pocket depth: 7.00.
- Optical through-window cut: 103.76 x 61.48.
- Lid view opening: 113.76 x 71.48.
- Nominal Rev C chip protrusion above the carrier top: 7.35.
- Nominal lid closure plane: 7.35 above the carrier top.
- Slot label land: 26.00 x 10.00 per slot, moved to the dry rear margin
  outside the gasket and leak-gutter zones.

Open issue for carrier/DFM agents: the manufacturing readiness note proposes 0.5-0.8 mm chip pocket clearance per side until real chip lot tolerance is measured. The current CAD uses 1.20 mm per side. Keep 1.20 mm as the A0 baseline for compatibility with the current generator, but resolve this before manufacturer drawings.

The 7.35 mm closure plane is not optional: it equals the nominal 14.35 mm chip
height minus the 7.00 mm pocket depth. Both carrier seal-land families and all
hard stops top out 7.35 mm above the carrier top and meet the lid sealing face at
closure. Each chip receives a 130.16 x 87.88 x 0.50 mm local underside relief so
the nominal chip top does not carry clamp load. That relief remains 2.20 mm from
the inner edge of its gasket groove in both X and Y. The 1.80 mm-deep lid groove
contains the 2.40 mm gasket at 25% nominal squeeze; it is a cavity above the
mating face, not an additional 1.80 mm plate-to-plate gap. Any chip-lot height,
pocket-depth, or underside-relief change requires an A0 revision plus a D7
section review.

## Datum Scheme

Use the cassette center as coordinate origin, but make physical registration
deterministic with a 3-2-1-style scheme:

| Datum | Physical feature | Function |
| --- | --- | --- |
| A | Carrier bottom plane seated directly on the dock support plane | Establishes Z seating and the carrier flatness reference; no spacer or recess offset is permitted in the active stack. |
| B | Nominal carrier rear edge against the dock rear-rail inner face | Primary in-plane datum. |
| C | Nominal carrier left edge against the dock left-rail inner face | Secondary in-plane datum, square to B. |
| Retention | Nominal carrier front edge against the front low retention lip | Prevents gross front lift or walkout without opposing B/C. |

- Carrier-to-lid alignment uses the four corner boss/ear locations, but only D1
  and a relieved or slotted D2 may be functional hard locators. D3 and D4 remain
  clearance/witness features unless an explicit revision proves the assembly is
  not overconstrained.
- Dock-to-bench/module alignment uses dock leveling-pad lands and perimeter mount
  holes; those features do not replace carrier datums A/B/C.

Current carrier datum pin boss centers:

| Datum | X | Y |
| --- | ---: | ---: |
| D1 front-left | -335.52 | -204.96 |
| D2 front-right | 335.52 | -204.96 |
| D3 rear-left | -335.52 | 204.96 |
| D4 rear-right | 335.52 | 204.96 |

Current datum boss assumptions:

- Boss diameter: 18.00.
- D1 round locator bore: 6.00 diameter.
- D2 relieved locator: 10.00 x 6.00 slot, oriented along X between D1 and D2
  so the pair constrains Y without overconstraining X.
- D3/D4 clearance/witness bores: 9.00 diameter; these are explicitly
  non-locating.
- Boss height: 6.00 above carrier top.

First-article assumption from A1: use a 6 mm stainless ground-dowel family, ream
the functional D1/D2 carrier features after drilling, use a round D1 and
relieved/slotted D2 strategy, and keep D3/D4 as clearance/witness holes. Final
bore tolerances and post-finish inspection remain drawing-release decisions.

The lid manufacturing part contains replaceable-pin seats, not integral pins.
D1 and D2 each use a 6.00 mm-diameter x 4.00 mm-deep lid seat for a 5.80 mm
fit-check pin surrogate. The surrogate is 7.35 mm long: 4.00 mm embedded in the
lid seat and 3.35 mm projecting below the lid, giving 2.00 mm engagement in the
carrier boss at closure. D3/D4 receive no pins or pin seats. Pin surrogates appear
only in assembly/stackup reference output; select the commercial pin SKU and
final fits before drawing release.
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

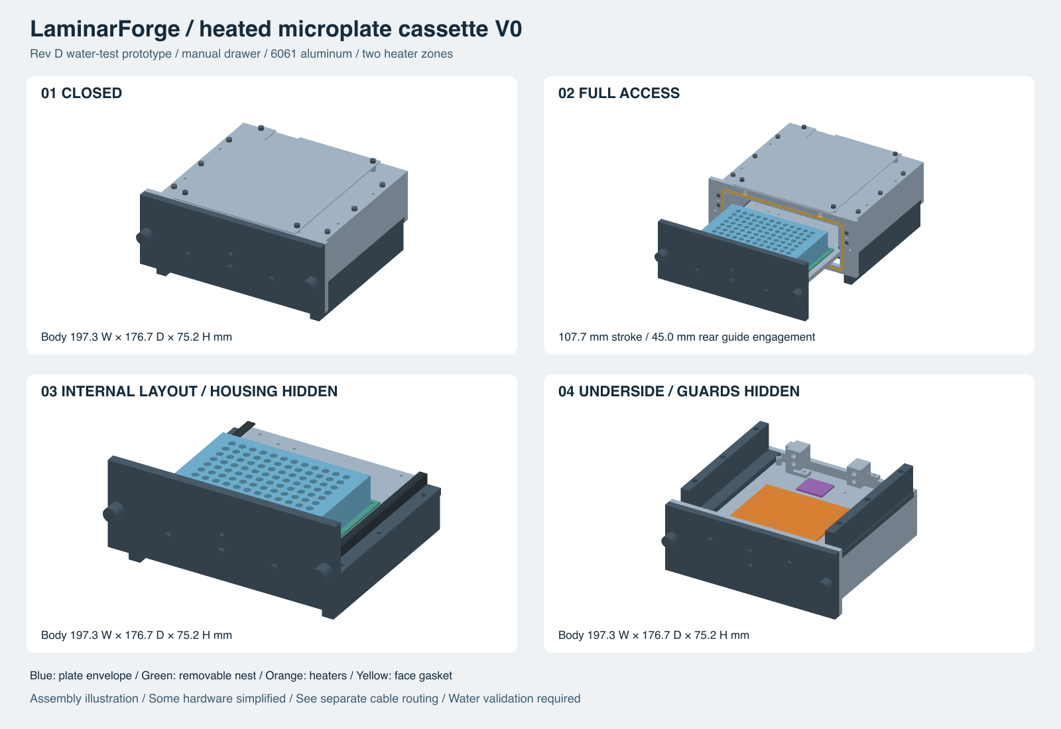
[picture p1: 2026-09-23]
docs/heated-cassette-v0/design-review.png

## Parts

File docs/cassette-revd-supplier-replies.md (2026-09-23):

# Rev D supplier replies — preparation record

Unsent. Attach the final verified Rev D supplier ZIP before creating/sending the
following replies. Do not attach the Rev C ZIP or a development output directory.
The import and drawing claims below must be checked against the final package.

## HLH — Kaysie

Reply to Gmail message `1a0b37d128f13496`, kaysie@hlhprototypes.com.

```text
Hi Kaysie,

Sorry for the delay. Please replace the original files with the attached Rev D package.

The fixed harness bracket has been re-exported and import-checked. The BOMs now use plain ASCII text, with a PDF assembly BOM included. The package contains individual STEP files, dimensioned part drawings, assembly views and quantities.

We also replaced the one-piece housing with four bolted plates to reduce machining cost. The finish is now clear sealed Type II anodizing, 5-15 microns; Type III is no longer required.

Please confirm the bracket and BOM open correctly, and quote one set and five sets with machining and finishing shown separately. Foam, tape, shim backing, hardware and electronics are owner supplied.

This remains a quote request only, with no authorization to fabricate.

Thanks,
Alex
```

## 3ERP — Nyla

Reply to Gmail message `1a0b356588269b23`, nyla@3erp.com.

```text
Hi Nyla,

Sorry for the delay. The attached Rev D package includes assembly drawings and BOM, individual part views and dimensions, labeled hole schedules, and feature details with the special tolerances on the drawings.

The base machining scope is 16 aluminum part designs, 26 pieces per set. The housing is now four bolted plates instead of one hollowed-out block. Please use these revised STEP files and drawings together and discard the earlier package.

Please quote one set and five sets, separating machining from clear sealed Type II anodizing, 5-15 microns. Type III is no longer required. The optional material profiles, foam, tape, shim backing, hardware and electronics are excluded from the base quote.

Please flag any remaining drawing conflicts or features that materially increase cost. This is a quotation request only.

Thanks,
Alex
```

## Prickly Pear — Benjamin

Reply in thread `1a0afdf4f7df33db`, bsimon@pricklypearprototypes.com.

```text
Hi Benjamin,

We have put the four-piece plate approach into the attached Rev D CAD and drawings. The roof and front bezel finish at 6 mm from 1/4-inch stock; the side plates finish at 18.5 mm from 3/4-inch stock, subject to your stock's cleanup allowance. The joints now have defined screws, dowels and tolerances.

Please use this package for the one-set and five-set quotes. Clear sealed Type II anodizing, 5-15 microns, is now the specified finish; Type III is no longer required. Please keep machining and finishing separate as discussed.

If a stock size, joint detail or tolerance is still driving cost, please mark the specific feature and proposed change. Foam, tape, shim backing, hardware and electronics are owner supplied. No fabrication is authorized yet.

Thanks,
Alex
```

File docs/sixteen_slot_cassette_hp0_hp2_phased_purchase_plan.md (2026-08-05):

# 16-Slot Cassette HP-0 Through HP-2 Phased Purchase Plan

Purchase plan ID: LF-CAS-A7-PR002
Revision: A0
Ticket: T-4D2B2A36
Source procurement register: [LF-CAS-A7-PR001 revision A0](sixteen_slot_cassette_hp0_hp2_procurement_list.md)
Governing readiness checklist: [LF-CAS-A7-RC001 revision A0](sixteen_slot_cassette_hp0_hp2_readiness_checklist.md)
Pricing basis date: 2026-08-04
Currency: 2026 USD, before sales tax except through the controlled reserve
Disposition: BUDGETARY PHASING RECOMMENDATION — NOT PURCHASE AUTHORIZATION

## Decision

Use one opening authorization, IA-1, with a maximum exposure of **$97,168**.
It contains $85,168 of item-level high-end commitments and a separately
controlled $12,000 reserve. The plan therefore remains **$2,832 below the
$100,000 ceiling** even if every IA-1 line commits at its current high estimate
and the entire reserve is used.

IA-1 is deliberately split into two release groups. Phase 0A addresses the
earliest HP-0 input and metrology blockers. Phase 1A buys or rents only the
core control, measurement, preparation, closure, and safety equipment after
the applicable HP-0 envelopes are frozen. Inclusion in IA-1 is not permission
to order before a row's release trigger.

Do not use IA-1 for the full-size cassette, functional/fault articles,
single-use harnesses, custom validation stations, destructive testing, or
the EQ-17 independent large-part first-article inspection campaign. Those
items remain in later, independently approved phases.

## Budget Architecture

| Authorization or phase | Purpose | Direct estimate | Authorization treatment |
| --- | --- | ---: | --- |
| IA-1 / Phase 0A | HP-0 controlled inputs and preliminary metrology | $17,600-$39,800 | Included; release now only as each R0 condition closes. |
| IA-1 / Phase 1A | Core selected bench, measurement, and safety equipment | $33,418-$45,368 | Included; conditional R1 releases only. |
| IA-1 direct line-item subtotal | Thirteen controlled rows | **$51,018-$85,168** | Sum of the source-register ranges; $85,168 is the direct commitment cap. |
| IA-1 central reserve | Tax, freight, calibration shipping, and approved within-row quote variance | **$12,000** | Held centrally; not preallocated and not available for new scope. |
| IA-1 maximum exposure | Direct high cap plus full reserve | **$97,168** | Hard stop; includes open POs and non-cancelable deposits. |
| Unallocated ceiling headroom | Difference from $100,000 | **$2,832** | Cannot be assigned without a controlled plan revision. |
| Phase 1B | HP-1 measurement-method and physical-interface closeout | $17,149-$21,700 | Separate later authorization. |
| Phase 2A | HP-1 functional, safety, and fault-system build | $52,000-$122,500 | Separate later authorization after R2 release. |
| Phase 2B | HP-1 gasket, leak, dye, and destructive controls | $25,300-$57,800 | Separate later authorization after R2 release. |
| Phase 3 | Production mechanical first article plus independent inspection | $30,025-$73,075 | Separate later authorization after R3 and the commercial risk gate. |
| Full direct baseline | All 20 EQ and 21 HW rows, without duplicates | **$175,492-$360,243** | Reconciles exactly to LF-CAS-A7-PR001; later phases do not imply approval. |

The $12,000 IA-1 reserve is not the full-program contingency. Every later
authorization requires refreshed quotes and its own contingency decision. The
full-program working envelope remains the $210,590-$432,292 range in
LF-CAS-A7-PR001 until controlled quotes replace it.

Committed spend means the maximum non-cancelable obligation, not only cash
already invoiced. It includes open purchase orders, rental minimums,
nonrefundable deposits, service cancellation fees, tax, freight, calibration
shipping, and supplier-held material that LaminarForge is obligated to buy.

## Phase 0A — Controlled Inputs And Preliminary Metrology

This phase is first because it produces HP0-E04 inputs needed to correct the
release candidate, close D7, and freeze the ranges used to select later
equipment. Appoint the responsible and independent roles before committing a
row.

| ID | Preferred route and exact quantity | Earliest blocked gate/evidence | Release trigger | Estimate | Lead after release |
| --- | --- | --- | --- | ---: | --- |
| EQ-18 | **Rent or contract**, do not buy, one qualified D8 tool set/campaign. Structure one capped campaign with preliminary input metrology and later D8 support; any second mobilization requires a revised quote. | HP-0 HP0-E04; later HP-2 HP2-E02 | ML/GD approve method, calibration identity, range, U, and access; use R0 reservation only before D8. | $7,500-$13,500 | 3-8 wk |
| HW-07 | Inventory first, then **buy** 16 intended Rev C chips plus every declared spare; four spares and 20 total are the planning case. | HP-0 HP0-04/HP0-E04 | PR/DA declare spare count and controlled chip identity; credit only conforming on-hand articles. | $8,000-$20,000 for 20 | 6-10 wk |
| HW-02 | **Buy** representative M4 closure, receiver, and 6 mm datum samples; place the exact controlled-lot balance only after D7 selection. | HP-0 HP0-E04/05; later HP-2 | Candidate identity approved for preliminary work; final lot waits for D7 and DS-02A1. | $100-$300 | 1-2 wk |
| HW-05 | **Outsource** gasket applications review and buy one identified prototype/first production lot only; no multi-material campaign. | HP-0 D2/D4, HP0-E04/05; later HP-1/2 | GA selected; compound, geometry, tolerance, splice, compatibility, and lot evidence included in the quote. | $2,000-$6,000 | 6-10 wk |

Phase 0A cap: **$39,800**. Start no-cost, revocable capability RFIs for EQ-17,
HW-01, EQ-01/02/03, and Phase 2 service providers in parallel, but do not pay a
deposit or release an orderable production file. Any reservation fee counts
against IA-1 when it becomes non-cancelable.

## Phase 1A — Core Bench And Measurement Backbone

Phase 1A remains inside IA-1 but is not an immediate shopping list. Release
each row only after its range, rating, interface, calibration, raw-data, and
projected-uncertainty requirements are recorded in the applicable HP0-08
through HP0-14 evidence and DS-02A1 downselection.

| ID | Preferred route and exact quantity | Earliest blocked gate/evidence | Release trigger | Estimate | Lead after release |
| --- | --- | --- | --- | ---: | --- |
| EQ-02 | **Buy** six synchronized, liquid-compatible gauge-pressure channel assemblies. | HP-0 HP0-15; HP-1 HP1-05 | HP0-08 freezes all six ranges, basis, common clock, and U target. | $6,600 | 1-19 wk; carry 19 until range is frozen |
| EQ-01 | **Buy** one pressure-limited controller system and rated source/relief/isolation package. | HP-0 HP0-15; HP-1 HP1-03/04 | HP0-08/09 freeze MOP, hard cap, source, relief, reservoir, and logging interfaces; SR reviews. | $8,000-$12,000 | 6-10 wk |
| EQ-04 | **Buy** one synchronized DAQ/logger system. | HP-0 HP0-15; HP-1 HP1-03/05 | EQ-01/02/08 signals and clock/raw-export requirements frozen. | $5,300-$5,600 | 1-2 wk if distributor stock is secured; direct supply may be 12-28 wk |
| EQ-03 | **Rent or contract**, do not buy for FA-1, one controlled pressure-reference set spanning all selected ranges. | HP-0 HP0-15; HP-1 HP1-05 | HP0-08 freezes installed, Pgasket, Pburst, ceiling, accuracy, and module ranges. | $2,500-$5,000 | 1-3 wk |
| EQ-06 | **Buy** one analytical balance and one low/mid/high check-weight set. | HP-0 HP0-15; HP-1 HP1-05 | HP0-09/13 freeze the smallest net mass, capacity, readability, and U bands. | $4,100-$4,500 | 2-6 wk |
| EQ-08 | **Buy** two calibrated four-wire Pt100 probes. | HP-0 HP0-15; HP-1 HP1-05 | HP0-07 freezes fluid/ambient conditions and EQ-04 input compatibility. | $468-$568 | about 4 wk plus calibration handling |
| EQ-12 | **Buy** one base calibrated preparation/QC set; exclude the optional viscosity method. | HP-0 HP0-15; HP-1 HP1-06 | HP0-07/13 freeze recipe, density method, volume tools, and check ranges. | $3,200-$4,200 | 1-3 wk |
| EQ-19 | **Buy** one calibrated torque driver. | HP-0 HP0-15/D7; HP-1/2 | HW-02 closure choice and D7 torque range/tolerance frozen away from endpoints. | $850-$1,200 | 1-3 wk |
| EQ-20 | **Buy** one core safety-station set, excluding HW-18. | HP-0 HP0-07/15; HP-1 | HP0-07/08 freeze chemistry, inventory, pressure, PPE, spill, electrical, and depressurization needs; SR approves. | $2,400-$5,700 | 1-3 wk materials; 4-6 wk if facility work is required |

Phase 1A cap: **$45,368**. The preferred retained assets are items that form
the repeatable bench backbone or require configuration-specific integration.
The pressure reference stays rented because FA-1 needs campaign-limited,
range-specific accredited capability and purchase would add approximately
$7,900-$10,400 above the rental allowance.

## Phase 1B — Measurement Methods And Short-Lead Interfaces

Authorize Phase 1B separately after DS-02A1 records the exact methods and
interfaces. Selection and written quotes may support HP-0; physical receipt,
installation, and commissioning must occur before the applicable HP-1 rows.

| ID | Preferred route and exact quantity | Earliest blocked gate/evidence | Release trigger | Estimate | Lead after release |
| --- | --- | --- | --- | ---: | --- |
| EQ-10 | **Buy/build**, do not rent, one fixed four-view optical system; its validated geometry and timebase must remain stable through the campaign. | HP-0 selection; HP-1 HP1-E05 | HP0-06/10/11 freeze witness zones, smallest prohibited bubble/leak, FOV, resolution, lighting, and clock proof. | $7,500-$9,000 | 4-6 wk |
| EQ-05 | **Outsource/contract first**, one independent measured-input reference method; buy a dedicated source balance only if the contracted method cannot meet U, range, schedule, or raw-data requirements. | HP-0 selection; HP-1 HP1-05 | HP0-07/09 freeze input range, interval, independence, and U. | $3,600-$5,000 | 2-6 wk |
| EQ-11 | **Outsource dye analysis first** if a qualified service returns raw absorbance, blanks, standards, checks, LOD/LOQ, recovery, identity, and turnaround; otherwise buy one visible spectrophotometer within the same cap. | HP-0 selection; HP-1 HP1-E07 | HP0-13 freezes dye, wavelength, range, controls, sample count, hold time, and analytical decision rule. | $4,700-$4,950 | 4-6 wk |
| HW-11A | **Buy** four matched reservoirs/bags. | HP-0 selection; HP-1/2 | Capacity, material, lot, headspace/vent, rating, connector, and maximum inventory frozen. | $184-$600 | 3-6 wk |
| HW-13 | **Buy** 16 service-position connectors/fittings or controlled caps. | HP-0 selection; HP-1/2 | G0-G3, M0-M6, and W0-W4 states, panel geometry, tubing, rating, valving, and dead volume frozen. | $400-$1,200 | 1-4 wk |
| HW-18 | **Buy/build** one segregated W0/W1/W3/W4 destination set. | HP-0 selection; HP-1 | HP0-12 freezes waste map, anti-backflow/anti-siphon method, capacity, and containment; SR reviews. | $615-$800 | 1-2 wk |
| HW-19 | **Outsource printing** for the first controlled label set unless compatible in-house equipment and validated stock already exist. | HP-0 selection; HP-2 identity | Identity scheme, cleaning chemistry, humidity exposure, substrate, adhesive, and print durability frozen. | $150 | 1-2 wk |

Phase 1B cap before its own contingency: **$21,700**.

## Phase 2A — Functional, Safety, And Fault-System Build

Release no Phase 2A order until the exact HP0-E06 drawings, P&ID, BOM,
materials, reference nodes, and methods reach R2 at HP0-15A. Dry receipt and
commissioning do not authorize wet work; SAF-E01 and SAF-E02 remain separate.

| ID | Preferred route and exact quantity | Gate blocked | Release trigger | Estimate | Lead after release |
| --- | --- | --- | --- | ---: | --- |
| EQ-09 | **Buy/build** one calibrated injector serving exactly five selectable locations; contract calibration where useful. | HP-0/1 | R2 HP0-E06 plus frozen gas volume, P/T correction, selector, and U. | $2,500-$4,000 | 4-8 wk |
| EQ-13 | **Outsource custom fabrication/integration** of one measured waste/backpressure station; retain the accepted station. | HP-0/1 | R2 P&ID/BOM, positions, head/backpressure ranges, W4 stimulus, drain, and containment interfaces released; SR reviews. | $4,600-$9,500 | 4-8 wk |
| EQ-14 | **Outsource fabrication** of one installed-system safety rig and retain it for repeat commissioning. | HP-0/1 | R2 pressure boundary, hard cap, interlock, relief, isolation, containment, and derating package released; SR approves. | $7,600-$16,000 | 6-10 wk |
| EQ-07 | **Buy/fabricate** 16 covered vessels, 16 keyed positions, and at least three matched blanks/positions. | HP-1 | R2 volume/material/cover/visibility/tare/evaporation method released. | $900-$2,000 | 1-4 wk |
| HW-10A | **Outsource fabrication** of one fixture mechanical set; retain the accepted assembly. | HP-1 | R2 datum nest, pressure-bar, deck, mounts, tray, and FAI requirements released. | $8,000-$20,000 | 6-10 wk |
| HW-10 | **Buy/integrate or outsource** one externally accessible 16-selection fault manifold. | HP-0/1 | R2 blind key, reference nodes, wetted volume/material/rating, and non-disturbing switching proof released. | $6,000-$15,000 | 8-12 wk |
| HW-11 | **Outsource assembly** of four complete controlled single-use harnesses; do not reduce quantity without prospective reconnect qualification. | HP-0/1/2 | R2 topology, materials, lots, ratings, proof/leak record, and four checkpoint identities released. | $16,000-$40,000 | 6-10 wk |
| HW-12 | Receive four complete topologies **included in HW-11**; no separate PO. | HP-0/1/2 | Same release and receipt control as HW-11. | $0 incremental | 6-10 wk |
| HW-08 | **Outsource fabrication and characterization** of 16 serialized nominal functional surrogates. | HP-1/2 | R2 footprint, flow-through path, finite resistance band, materials, ratings, U, and identity released. | $4,000-$9,600 | 4-8 wk |
| HW-09 | **Outsource fabrication and characterization** of 16 serialized fault coupons: four each low, high, blocked, and bypass. | HP-1 | R2 class bands, row/column map, one-sided blocked limit, materials, ratings, and U released. | $2,400-$6,400 | 4-8 wk |
| HW-17 | Receive the vessel/blank inventory **included in EQ-07**; no separate PO. | HP-1 | Same release and receipt control as EQ-07. | $0 incremental | 1-4 wk |

Phase 2A cap before its own contingency: **$122,500**.

## Phase 2B — Gasket, Leak, Dye, And Destructive Controls

Phase 2B follows the same R2 control but is commercially separated so the
highest-risk destructive and analytical work cannot consume functional-rig
funds. Release the physical coupon/control work before the destructive service
slot so the service quote is tied to accepted article identities.

| ID | Preferred route and exact quantity | Gate blocked | Release trigger | Estimate | Lead after release |
| --- | --- | --- | --- | ---: | --- |
| EQ-15 | **Outsource as a physically separate destructive-test service** for FA-1; do not buy a dedicated rig unless no qualified service meets ratings, raw capture, safety, independence, and schedule. | HP-0/1 | R2 destructive method, pressure hierarchy, hard ceiling, source volume, capture rate, shielding, containment, and abort package released; SR approves. | $12,600-$27,000 | 8-12 wk |
| EQ-16 | **Outsource** one leak-method characterization/control service set. | HP-0/1 | Leak medium, threshold, trapped volume, dye tray/witness method, controls, and raw-data requirements frozen. | $1,700-$3,300 | 5-8 wk |
| HW-06 | **Outsource fabrication** of one production-intent coupon set for the single selected gasket material/lot. | HP-1 | D4, D7, exact gasket lot, groove/finish/stop/fastener geometry, FAI, and serialization released. | $2,000-$6,000 for 1 set | 3-6 wk |
| HW-14 | **Outsource fabrication** of one matched sealed-fixture blank. | HP-1 | Boundary, fittings, materials, temperature, trapped volume, and no-leak verification released. | $500-$1,500 | 3-6 wk |
| HW-15 | **Outsource fabrication and independent calibration** of one permanent artificial-leak control. | HP-1 | Smallest rejectable leak, medium, pressure, temperature, stability, and calibration method frozen. | $500-$2,000 | 4-8 wk |
| HW-16 | **Outsource build/integration** of one quantitative dye/mass-closure and hold-up station; retain the accepted station. | HP-1 | R2 fraction map, switching/reset, mass ledger, materials, ratings, and no-hidden-mixing proof released. | $8,000-$18,000 | 8-12 wk |

Phase 2B cap before its own contingency: **$57,800**. Phase 2A plus 2B
reconciles to **$77,300-$180,300**.

## Phase 3 — Production First Article And Independent Inspection

The formal R3 prerequisite is HP0-15B: matching released D0-D9 drawings, STEP
files, final D7, D8, BOM, and manifests. This plan adds a stricter commercial
risk hold: do not release HW-01 until the selected-lot production-intent
gasket/coupon evidence has no unresolved critical failure. Removing this hold
requires a prospective controlled revision; it cannot be waived ad hoc. The
hold changes procurement timing, not a technical acceptance requirement.

| ID | Preferred route and exact quantity | Gate blocked | Release trigger | Estimate | Lead after release |
| --- | --- | --- | --- | ---: | --- |
| HW-01 | **Outsource machining/finishing** of one serialized matched carrier/lid/window/bulkhead/dock set with vendor FAI. | HP-2 | R3 HP0-15B, no unresolved selected-lot gasket/coupon critical, controlled RFQ/PO, and independent inspection slot confirmed. | $25,000-$60,000 | 6-10 wk after released package |
| EQ-17 | **Outsource**, do not buy, one independent large-part CMM/vision inspection campaign separate from vendor FAI. | HP-2 HP2-E02 | D8 released; accepted machine envelope, access, U, programming, raw data, calibration identity, and chain of custody. | $4,000-$9,000 | 2-6 wk |
| HW-04 | **Outsource fabrication/buy** one retained-window hardware set. | HP-2 | D3 retention, load path, seal, cleaning, visibility, installation, and inspection requirements released. | $1,000-$4,000 | 4-8 wk |
| HW-03 | **Buy** six M5 dock fastener stacks only if D5 retains them; otherwise obtain prospective QR-approved N/A. | HP-0/2 | D5 exact length/head/material/retention/engagement/torque/finish released. | $25-$75 | 1-2 wk |

Phase 3 cap before its own contingency: **$73,075**.

## Buy, Rent, Outsource, And Defer Decisions

| Route | Controlled rows | Decision |
| --- | --- | --- |
| Buy and retain in IA-1 | EQ-01, EQ-02, EQ-04, EQ-06, EQ-08, EQ-12, EQ-19, EQ-20; HW-02 and HW-07 inputs | These are repeatable bench-backbone assets or controlled physical inputs. Buy only after exact selection; an on-hand credit requires the same identity, calibration, rating, and evidence as a purchase. |
| Rent/contract in IA-1 | EQ-03 and EQ-18 | Campaign-specific calibrated capability is cheaper and avoids owning range-specific or specialized metrology. Purchase is deferred. |
| Outsource specialized service | EQ-05, EQ-11 when qualified, EQ-15, EQ-16, EQ-17; HW-05 engineering and HW-15 calibration | Use only providers that return required raw/native data, calibration identity, methods, chain of custody, and change control. Supplier FAI never replaces EQ-17 independence. |
| Outsource controlled fabrication; retain deliverable | EQ-13, EQ-14; HW-01, HW-04, HW-06, HW-08, HW-09, HW-10A, HW-11, HW-14, HW-16 | Released drawings/BOMs and controlled POs govern these builds. Outsourcing does not relax incoming inspection or acceptance. |
| Buy/build after initial authorization | EQ-07, EQ-09, EQ-10; HW-10, HW-11A, HW-13, HW-18, HW-19 | Needed only after their methods and interfaces freeze; short leads or configuration dependence make early ordering poor risk. |
| Included, no separate spend | HW-12 with HW-11; HW-17 with EQ-07 | Maintain separate identity and acceptance rows but prohibit duplicate POs. |
| Explicitly deferred outside IA-1 | EQ-05, EQ-07, EQ-09, EQ-10, EQ-11, EQ-13, EQ-14, EQ-15, EQ-16, EQ-17; HW-01, HW-03, HW-04, HW-06, HW-08, HW-09, HW-10, HW-10A, HW-11, HW-11A, HW-12, HW-13, HW-14, HW-15, HW-16, HW-17, HW-18, HW-19 | Deferred means not initially funded, not removed from LF-CAS-A7-RC001. Each returns only at the phase trigger above. |

The following remain deferred outside the 41-row core baseline:

- the $5,500-$6,000 viscosity bath/viscometer method unless HP0-07 retains
  viscosity-adjusted fluid;
- purchasing EQ-03 instead of renting it, which would add approximately
  $7,900-$10,400 for FA-1;
- owned large-volume CMM or broad D8 metrology capacity in place of EQ-17/18
  services;
- additional gasket-material coupon sets at $2,000-$6,000 per material/lot;
- a second full cassette set, confirmation lots, production scale, and extra
  run consumables; and
- all E1 environmental-extension and E2 hazardous-chemistry equipment.

Reconsider an owned pressure reference, metrology asset, spectrophotometer, or
destructive rig only after at least two later approved campaigns have defined
the same range/method and a documented 24-month total-cost comparison includes
purchase, calibration, maintenance, storage, software, operator competency,
downtime, and independence. Lower sticker price alone is not a justification.

## IA-1 Commitment Ledger And Release Rules

SL must maintain a live IA-1 ledger with, at minimum, row ID, supplier,
quote/version, route, committed amount, tax, freight, calibration shipping,
deposit/cancellation exposure, expected receipt, gate trigger, receipt state,
and remaining direct/reserve/headroom balances.

Apply these rules to every commitment:

1. Record the full non-cancelable exposure before issuing the PO, rental, or
   service authorization. Stop if direct commitments would exceed $85,168 or
   total exposure including approved reserve use would exceed $97,168.
2. Use the $12,000 reserve only for tax, freight, calibration shipping, or a
   documented within-row quote variance. It cannot fund a later-phase row,
   quantity increase, optional method, facility expansion, or acceptance-limit
   change.
3. Savings on one row remain uncommitted. They may cover another IA-1 row only
   within that row's existing high cap; they do not advance a deferred row.
4. A quote above a row's high estimate requires an identical-scope rebid,
   route comparison, and prospective PR/QR plan revision. Do not silently use
   reserve to hide a scope or specification mismatch.
5. Inventory is a $0 procurement credit only after ML/FV/GD, as applicable,
   confirms exact identity, quantity, condition, range, rating, calibration,
   uncertainty, software/firmware, compatibility, and raw-data capability.
6. A rental or service deposit counts at its maximum nonrefundable amount. A
   no-cost capacity hold stays at $0 only while it is fully revocable.
7. Every custom PO requires no unapproved substitution, material/process and
   sub-supplier change notification, raw data, calibration IDs, lot/serial
   traceability, FAI where applicable, NCR control, and chain of custody.
8. A provider that will not return required raw evidence or preserve the
   assigned independence is disqualified. Missing capability leaves the gate
   NOT READY; it does not authorize an unqualified fallback.
9. Lead-time pressure never permits ordering HW-01 or an R2 article from an
   unreleased package. Rebid, reserve a later slot, or accept the schedule slip.
10. Any selected range, material, interface, method, software, or supplier
    change reopens the affected checklist rows and invalidates downstream
    commitments until prospective review closes.

## Authorization Checkpoints

| Checkpoint | Minimum evidence before commitment | Approval record |
| --- | --- | --- |
| IA-1 opening | Named GD, ML, FV, TO, SR, QR, RC, and GA roles in addition to the current PR/DA/SL assignments; independence record complete; ledger opened; row caps loaded; Phase 0A quotes match the controlled scope. | PR authorizes envelope; SL accepts ledger duty; QR confirms release logic. |
| Each Phase 0A order | Row-specific R0 trigger, exact quantity/identity, traceability, and preliminary method acceptance. | Technical owner plus SL; QR release check; SR where safety-relevant. |
| Each Phase 1A order | Applicable HP0-08 through HP0-14 envelope and DS-02A1 exact downselection; projected U and calibration plan. | Technical owner plus SL; independent QR; SR for pressure/safety rows. |
| Phase 1B | HP0-15 downselection and method/interface freeze; refreshed written quotes and separate phase contingency. | New PR authorization; QR and applicable SR review. |
| Phase 2A/2B | R2 HP0-E06/HP0-15A package and dry-proof evidence; exact custom RFQs and incoming plans. | Separate authorization per subphase; QR and SR approval. |
| Phase 3 | R3 HP0-15B plus commercial gasket/coupon risk gate; vendor FAI and independent inspection POs both ready. | Separate PR authorization; DA/GD/GA/ML evidence; independent QR release. |

This plan changes only procurement timing and commercial route. It does not
change any quantity, specification, sample size, hold point, acceptance limit,
independence requirement, or failure-response rule in LF-CAS-A7-RC001,
LF-CAS-A7-PR001, or LF-CAS-A7-P001.

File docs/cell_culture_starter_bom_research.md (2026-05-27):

# Cell Culture Starter BOM Research

This is a practical sourcing snapshot for the starter cell-culture equipment matrix. It is not a purchasing approval list; final selections still need datasheet review, fit checks, and facility biosafety approval where applicable.

| Category | Practical starter examples | Rough cost | Decision | Notes |
| --- | --- | ---: | --- | --- |
| CO2 sensor/control | CO2Meter ExplorIR-M 20%, SprintIR/SprintIR-R 20%, Micro-Hybrid MicroSENS 180-HS 0-20% incubator sensor | $197-$550 starter/OEM; MicroSENS roughly EUR 834-EUR 1,276 | Build control module | Use 0-20%, not MH-Z19B. 5% CO2 is 50,000 ppm. MicroSENS is closer to real incubator OEM spec; ExplorIR-M is a more practical starter module. |
| Independent CO2 analyzer | Bacharach Fyrite 0-20% CO2 analyzer/test kit or borrowed/rented calibrated analyzer | About $760 when available | Buy/access | Use as independent validation, not the controller sensor. |
| Sample pump | CO2Meter micro-pump kit, Universal Analyzers Mini DiaVac, Hilintec C30/D27 gas sampling pumps | $30-$250+ | Build module | Keep outside humid chamber. Use low flow, condensate protection, and filters. |
| Hydrophobic/sterile filters | Cytiva Whatman ReZist 50 mm sterile 0.2 um PTFE, Sartorius Minisart PTFE 0.2 um, Merck/Sigma Millex-FG 50 mm PTFE, Corning 431227 sterile PTFE | $5-$25/filter depending pack | Buy | Use on sample path and vacuum/aspirator protection. 50 mm PTFE vent filters are better than small syringe filters for vacuum lines. |
| CO2 regulator/solenoid | AQUATEK paintball regulator with solenoid, FZONE aquarium regulator, Milwaukee MA957, CO2Art dual-stage regulator | $60-$250 | Buy | Aquarium/paintball parts are acceptable for prototype injection only with check valve, restrictor/needle valve, leak testing, and pressure relief. Move toward proper CGA-320 regulator for lab credibility. |
| Temp/RH logger | Lascar/DataQ EL-SIE, Elitech GSP-6G, Monarch Track-It with optional NIST certificate | $130-$300 plus calibration | Buy | Independent logger is mandatory. RH probes in incubators need droplet protection and may be consumable. |
| Water bath safety | Commercial Thermo/PolyScience/VWR/MSE Pro bath, or low-voltage DIY heater with GFCI, fuse, thermal cutoff, low-water switch, and independent thermometer | DIY $60-$200; commercial $300-$1,500+ | Buy or cautious build | Water plus mains power is high risk. Prefer low-voltage heating and an external GFCI. Independent over-temperature cutoff is not optional. |
| Aspirator/vacuum trap | Two-flask trap train with disinfectant collection flask, secondary overflow flask, inline hydrophobic HEPA/PTFE filter, Welch Biovac/Aspire class aspirator | DIY support $100-$300; commercial $500-$1,500+ | Buy/build holder only | Build brackets/tray, not the biosafety logic. Protect the pump or house vacuum and follow disinfectant contact-time rules. |
| PPE/waste basics | Lab coat/gown, nitrile gloves, eye protection, biohazard bags, sharps container, disinfectant, spill kit, liquid waste bottle/trap | $150-$500 starter | Buy | Facility biosafety rules override this list. No DIY disposal assumptions for human, iPSC, or viral workflows. |
| Microscope | Accu-Scope EXI-310 inverted phase contrast, Globe/Oxion Inverso, AmScope IN330TC class | $2,000-$5,000+ | Buy/access | Must be inverted phase contrast for routine mammalian culture. Brightfield upright scope is not sufficient for flasks/plates. |
| Centrifuge | Drucker BOOST 4, Eppendorf 5702/5810 class, clinical/bench centrifuge with 15/50 mL support | $2,000-$8,000+ | Buy | Do not DIY centrifuges. Use correct RCF, rotor/bucket compatibility, imbalance safety, and cleanable carriers. |
| Automated liquid handling path | Syringe/peristaltic pumps, sterile tubing, reservoirs, sterile connectors, chip fixtures | Prototype path varies; pump/channel and sterile disposable path dominate cost | Build/buy | Primary LaminarForge process target. Validate flow rates, leaks, bubbles, dead volume, and disposable sterile path before live culture. |
| Pipettes | Gilson PIPETMAN P20/P200/P1000, Rainin Classic, Eppendorf Research plus, pipette aid | Refurb $300-$700; new $900-$1,500+ | Buy only for debug/calibration | Not part of the intended process. Keep only for calibration, setup, rescue, and non-production validation work. |

## CAD Impact

- `co2_sensor_service_module` stays dimensionally provisional until the exact 0-20% NDIR sensor, pump, filters, and fittings are selected.
- `aspirator_waste_trap_holder` is a mechanical support part only. It does not validate disinfectant chemistry, contact time, biosafety containment, or disposal.
- `cell_culture_logger_enclosure` should house independent validation logging, not the incubator control loop.
- Do not put the DIY incubator, still-air enclosure, aspirator holder, or printed centrifuge adapters on the website as culture-ready equipment.

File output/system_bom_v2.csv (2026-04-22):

Category | Part | Mfr | Mfr PN | Distributor | Distributor URL | Qty | Unit Cost USD | Extended Cost USD | Lead Time | Notes
Structural | 6061-T6 aluminum sheet 3mm 600x500 | Ryerson | 6061-3MM-SHEET | McMaster-Carr | https://www.mcmaster.com/8975K241/ | 5 | 38.00 | 190.00 | 3-5 days | 5 chip-rack shelves; 535.6 x 458.4 x 3 mm water-jet or laser cut
Structural | 6061-T6 aluminum sheet 6mm 600x500 (rack base + rocker base/top) | Ryerson | 6061-6MM-SHEET | McMaster-Carr | https://www.mcmaster.com/8975K245/ | 3 | 95.00 | 285.00 | 3-5 days | Rack base 545x495x6; rocker base 560x490x10 (use 10mm); rocker top 500x440x8
Structural | 6061-T6 10mm plate for rocker base | Ryerson | 6061-10MM-PLATE | McMaster-Carr | https://www.mcmaster.com/8975K252/ | 1 | 110.00 | 110.00 | 3-5 days | Rocker base plate CNC milled 560x490x10 mm
Structural | 20x20x2 aluminum square tube 6m | Metals Depot | 6061-SQ-TUBE-20x20 | McMaster-Carr | https://www.mcmaster.com/6546K42/ | 1 | 52.00 | 52.00 | 3-5 days | Cut 4x 230 mm corner posts for chip rack
Structural | 10mm stainless rod 1m (carry handle) | Metals Depot | SS-ROD-10MM-1M | McMaster-Carr | https://www.mcmaster.com/8920K25/ | 1 | 14.50 | 14.50 | 3 days | Bend into U handle for rack
Structural | 3mm PETG sheet 1000x600 (for FDM alt parts + tray) | Vistaplex | PETG-3MM-CLEAR | McMaster-Carr | https://www.mcmaster.com/8567K84/ | 4 | 45.00 | 180.00 | 3-5 days | Chamber + shell walls if not printed; water tray; drip tray
Structural | 25 mm PIR insulation sheet Kingspan Kooltherm K5 2400x1200 | Kingspan | KOOLTHERM-K5-25 | Kingspan (distributor Builder Depot) | https://www.kingspan.com/us/en/products/insulation/ | 2 | 78.00 | 156.00 | 5-7 days | Chamber walls (6 sides) + door foam core; ~2.5 m² total
Structural | Acrylic window 300x200x4 mm clear | Plaskolite | ACRYL-4MM-300x200 | McMaster-Carr | https://www.mcmaster.com/8560K277/ | 1 | 22.00 | 22.00 | 3 days | Door viewing window
Structural | Silicone cord gasket 3 mm x 10 m | McMaster | 8694K26 | McMaster-Carr | https://www.mcmaster.com/8694K26/ | 1 | 38.00 | 38.00 | 3 days | Door + hatch gaskets; food-grade silicone
Structural | 8 mm Neodymium magnets N52 10-pack | K&J Magnetics | D48 | Amazon | https://www.amazon.com/dp/B0744R9N81 | 1 | 12.99 | 12.99 | 2 days | Door magnetic latches (4x door + 2x hatch)
Structural | 6 mm steel hinge pin 100 mm (pack of 4) | McMaster | 98381A576 | McMaster-Carr | https://www.mcmaster.com/98381A576/ | 1 | 8.50 | 8.50 | 3 days | Door hinge
Structural | M6 leveling feet with M6 stud 4-pack | McMaster | 23015T42 | McMaster-Carr | https://www.mcmaster.com/23015T42/ | 1 | 18.00 | 18.00 | 3 days | Enclosure leveling
Structural | Assorted M3/M4/M5/M6 SS hex-cap screws, washers, nuts kit | McMaster | 92220A795 | McMaster-Carr | https://www.mcmaster.com/92220A795/ | 1 | 95.00 | 95.00 | 3 days | ~400 pc hardware for rack/rocker/incubator assembly
Structural | Sorbothane 8x2 mm isolation feet 4-pack | Sorbothane | SOR-8-2-4PK | Amazon | https://www.amazon.com/dp/B01L2B082I | 2 | 15.99 | 31.98 | 2 days | Rocker base vibration isolation
Structural | PETG 3D printing filament 5 kg (for printed parts) | Prusament | PR-PETG-5KG | Prusament | https://prusament.com/petg/ | 2 | 64.00 | 128.00 | 7 days | Chamber, manifold, drip heads, posts, etc.
Thermal control | 200 W silicone heater pad 300x300 mm 120 VAC | OMEGA | SRFG-304/10-A | McMaster-Carr | https://www.mcmaster.com/35765K76/ | 1 | 98.00 | 98.00 | 3-5 days | Primary chamber heater; PSA back
Thermal control | Crydom D2425 AC SSR 25A 240VAC zero-cross | Sensata-Crydom | D2425 | Digikey | https://www.digikey.com/en/products/detail/sensata-crydom/D2425/139477 | 1 | 44.50 | 44.50 | 1 week | Main heater switching element; DIN-rail mount
Thermal control | Crydom DC60S5 DC SSR 5A for pre-stage | Sensata-Crydom | DC60S5 | Digikey | https://www.digikey.com/en/products/detail/sensata-crydom/DC60S5/726895 | 1 | 32.00 | 32.00 | 1 week | Backup/secondary low-current switching
Thermal control | KSD9700 100C NC bimetallic thermostat (safety) | Generic | KSD9700-100C | LCSC | https://www.lcsc.com/product-detail/Temperature-Sensors_KEAC-KSD9700-100-C-NC_C2909862.html | 2 | 0.60 | 1.20 | 3 weeks | Hardware safety interlock per PCB spec; 1 for board + 1 spare
Thermal control | 55C bimetallic switch (overtemp signal) | Honeywell | 2450R | Digikey | https://www.digikey.com/en/products/detail/honeywell-sensing-and-productivity-solutions/2450R/6138054 | 1 | 11.25 | 11.25 | 1 week | GPIO10 OVERTEMP_SW input
Thermal control | ITO-coated heated glass 50x50x1.1mm | Diamond Coatings | ITO-50-70 | Adafruit | https://www.adafruit.com/product/4377 | 1 | 18.95 | 18.95 | 3 days | Imaging-head anti-condensation window
Thermal control | ITO-coated heated glass 300x200 (door window anti-fog) | Sigma Koki / Diamond Coatings | ITO-300x200 | Diamond Coatings custom | https://diamondcoatings.com/contact/ | 1 | 185.00 | 185.00 | 2-3 weeks | Optional upgrade to acrylic for anti-fog; alt: resistive heater wire
Thermal control | Anti-condensation heater wire Kapton 24 V 10 W/m (5 m) | OMEGA | KHLV-102/10 | OMEGA | https://www.omega.com/en-us/heaters/surface-heaters/kapton-heaters/p/KHLV-Series | 1 | 48.00 | 48.00 | 1 week | Door anti-fog + hatch anti-condensation channels
Thermal control | NTC thermistor 10k beta 3950 (5-pack) | Adafruit | ADA372 | Adafruit | https://www.adafruit.com/product/372 | 1 | 16.95 | 16.95 | 3 days | Imaging window closed-loop temp sense
Environmental | MH-Z19B NDIR CO2 sensor 0-5% | Winsen | MH-Z19B | Digikey | https://www.digikey.com/en/products/detail/winsen-electronics-tech-co-ltd/MH-Z19B/10244833 | 1 | 35.00 | 35.00 | 1 week | Chamber CO2 sensing via UART
Environmental | SHT40 temp + humidity sensor | Sensirion | SHT40-AD1B | Digikey | https://www.digikey.com/en/products/detail/sensirion-ag/SHT40-AD1B-R2/10130685 | 2 | 3.85 | 7.70 | 1 week | Chamber RH + backup on imaging head
Environmental | DS18B20 waterproof 1-Wire temp probe | Maxim | DS18B20 | Adafruit | https://www.adafruit.com/product/381 | 2 | 9.95 | 19.90 | 3 days | Secondary temp + heater-block temp
Environmental | 5 lb CO2 aluminum bulk tank + solenoid regulator dual stage | CO2Doctor | CD-5LB-DUAL | Amazon | https://www.amazon.com/dp/B07X3HH1RX | 1 | 189.00 | 189.00 | 3 days | 5 lb / 2.3 kg tank; 26 refills/yr
Environmental | CO2 solenoid valve 12V 1/4 NPT (normally closed) | US Solid | JQRV-1/4-NC-DC12V | Amazon | https://www.amazon.com/dp/B07DLKZ4TG | 1 | 22.99 | 22.99 | 2 days | Inlet dosing under PWM
Environmental | 1/8 inch CO2 tubing polyurethane 10 ft | Freelin-Wade | 1R-100-08-Blue | Amazon | https://www.amazon.com/dp/B0854JQVQN | 1 | 12.99 | 12.99 | 2 days | Tank to chamber inlet
Environmental | 80 mm axial fan 12 V 0.25 A ball bearing | Noctua | NF-A8 PWM | Digikey | https://www.digikey.com/en/products/detail/noctua/NF-A8-PWM/7873298 | 1 | 17.95 | 17.95 | 1 week | Chamber internal circulation
Environmental | Millex-FG 0.2 um PTFE 50 mm HEPA vent filter (10 pack) | Millipore | SLFG05010 | Millipore | https://www.emdmillipore.com/US/en/product/Millex-FG-Syringe-Filter-Unit/MM_NF-SLFG05010 | 1 | 98.00 | 98.00 | 1 week | Media reservoir + waste bottle vents
Environmental | Omron E3F-DS30C4 optical beam sensor M12 | Omron | E3F-DS30C4 | Digikey | https://www.digikey.com/en/products/detail/omron-automation-and-safety/E3F-DS30C4/1025285 | 1 | 58.00 | 58.00 | 1-2 weeks | Reservoir low-level detect
Environmental | Humidity water tray (2.5 mm PETG fabricated) | In-house | INT-HTRAY-01 | In-house 3D print |  | 1 | 0.00 | 0.00 | 1 day | Covered by PETG filament line above
Rocker mechanics | NEMA 17 stepper motor 1.8 deg 2 A (rocker) | StepperOnline | 17HS19-2004S1 | Amazon | https://www.amazon.com/dp/B07M66J2D3 | 1 | 18.99 | 18.99 | 2 days | Rocker drive; torque sufficient per artifact math (NEMA23 preferred for higher margin)
Rocker mechanics | NEMA 23 stepper motor 1.8 N-m (upgrade rocker) | StepperOnline | 23HS30-2804S | StepperOnline | https://www.omc-stepperonline.com/nema-23-bipolar-1-8deg-2-8a-23hs30-2804s | 1 | 39.50 | 39.50 | 5-7 days | Rocker drive upgrade to original spec
Rocker mechanics | NEMA 17 stepper 5 x for pump manifold | StepperOnline | 17HS19-1684S-PG5 | Amazon | https://www.amazon.com/dp/B00PNEQ9Y4 | 5 | 18.99 | 94.95 | 2 days | 1 per Kamoer pump head (5 channels)
Rocker mechanics | TMC2209 stepper driver SilentStepStick 2.8 A | BIGTREETECH | TMC2209-V3.0 | Amazon | https://www.amazon.com/dp/B084ZF7PMD | 6 | 10.99 | 65.94 | 2 days | 1 rocker + 5 pumps
Rocker mechanics | Arduino-compatible stepper carrier board (for 6 drivers) | BIGTREETECH | SKR-Mini-E3-V3 | Amazon | https://www.amazon.com/dp/B09JNWYDBP | 1 | 45.00 | 45.00 | 2 days | Runs Klipper/Marlin; interfaces via UART to ESP32
Rocker mechanics | 8 mm acme lead screw 2 mm lead 300 mm | Misumi | MTSRA8-300-P2 | McMaster-Carr | https://www.mcmaster.com/99030A103/ | 1 | 22.50 | 22.50 | 3 days | Rocker drive leadscrew
Rocker mechanics | Flanged POM acme nut 22 mm OD M4 mount | StepperOnline | POM-ACME-22-M4 | Amazon | https://www.amazon.com/dp/B08B6V8TRW | 1 | 9.95 | 9.95 | 2 days | Leadscrew nut
Rocker mechanics | R3-2RS radial ball bearing 19x9.525x5 (10 pack) | VXB | R3-2RS-10 | VXB | https://www.vxb.com/R3-2RS-Sealed-Bearing-p/R3-2RS.htm | 1 | 24.95 | 24.95 | 3 days | Pivot bearings
Rocker mechanics | F688ZZ flanged bearing 8x16x5 (10 pack) | VXB | F688ZZ-10 | VXB | https://www.vxb.com/F688ZZ-Flange-Ball-Bearing-p/F688ZZ.htm | 1 | 19.95 | 19.95 | 3 days | Lead-screw end bearings
Rocker mechanics | 6.35 to 8 mm flexible jaw shaft coupler | Ruland | MWC20-8-1/4 | McMaster-Carr | https://www.mcmaster.com/9861T72/ | 1 | 18.95 | 18.95 | 3 days | Stepper-to-leadscrew
Rocker mechanics | 8 mm x 50 mm precision dowel shaft (10 pack) | McMaster | 6061K161 | McMaster-Carr | https://www.mcmaster.com/6061K161/ | 1 | 14.95 | 14.95 | 3 days | Pivot shafts
Rocker mechanics | Microswitch limit switch 12 V SPDT (5 pack) | Honeywell | V7-1B17D8 | Amazon | https://www.amazon.com/dp/B07HB3MSDN | 1 | 9.99 | 9.99 | 2 days | Lead-screw home + limit
Media delivery | Kamoer KCS-B peristaltic pump head NEMA17 mount | Kamoer | KCS-B-S13-K | Cole-Parmer | https://www.coleparmer.com/s?q=kamoer+kcs | 5 | 95.00 | 475.00 | 2-3 weeks | 5 independent pump heads for 5-shelf dosing
Media delivery | Platinum-cured silicone tubing 1.6 mm ID x 4.8 mm OD x 50 ft | Masterflex | 96420-13 | Cole-Parmer | https://www.coleparmer.com/i/masterflex-l-s-platinum-cured-silicone-pump-tubing-l-s-13-50-ft/9642013 | 1 | 165.00 | 165.00 | 3-5 days | Masterflex L/S 13 equivalent
Media delivery | CPC AseptiQuik DC 1/4 hose barb connector (pair) | CPC Worldwide | AQCDC17004 | Cole-Parmer | https://www.coleparmer.com/i/cpc-colder-aseptiquik-g-dc-quick-disconnect-fitting-genderless-hose-barb-polycarbonate-valved-1-4-id-1-each/5011174 | 6 | 55.00 | 330.00 | 1-2 weeks | 1 trunk + 5 drip-head QDs; gamma-sterile
Media delivery | PETG 8 L reservoir + lid (fabricated from sheet) | In-house | INT-RES-8L | In-house fabrication |  | 1 | 40.00 | 40.00 | 3 days | Or purchase Nalgene 8 L Carboy 2210-0020 $58
Media delivery | Nalgene 8 L autoclavable carboy (alt) | Nalgene | 2210-0020 | Cole-Parmer | https://www.coleparmer.com/i/nalgene-2210-0020-autoclavable-polycarbonate-carboy-8-l-each/0621304 | 1 | 58.00 | 58.00 | 3-5 days | Alt to printed reservoir; PC instead of PETG
Media delivery | Nalgene 4 L waste bottle with barbed vent cap | Nalgene | 2125-0010 | Cole-Parmer | https://www.coleparmer.com/i/nalgene-2125-0010-narrow-mouth-autoclavable-hdpe-bottle-4-l-each/0619502 | 1 | 18.50 | 18.50 | 3-5 days | External waste collection
Media delivery | Luer-lock barbed fittings 1/8 polypropylene (25 pack) | Cole-Parmer | 45518-00 | Cole-Parmer | https://www.coleparmer.com/i/cole-parmer-polypropylene-male-luer-lock-to-1-8-id-hose-barb-25-pk/4551800 | 1 | 28.50 | 28.50 | 3-5 days | Dip tubes + HEPA vent mating
Media delivery | Silicone grommet assembly 5-hole (1 pc custom) | Bumper Specialties | BS-5H-GROM | In-house cast |  | 1 | 15.00 | 15.00 | 1 week | Wall passthrough grommet
Media delivery | 1/4 NPT to 6 mm push-to-connect fitting (10 pack) | SMC | KQ2H06-02 | Amazon | https://www.amazon.com/dp/B01MXGZOYU | 1 | 16.99 | 16.99 | 2 days | Misc media + CO2 fittings
Chips + consumables | Rev C microfluidic chip glass coverslip bottom | MIMETAS (or custom PDMS) | OrganoPlate-2L | MIMETAS | https://www.mimetas.com/en/products/ | 100 | 25.00 | 2500.00 | 2-3 weeks | 100 chips for initial load; operational BOM handles reloads
Chips + consumables | Barcode labels 10x5 mm adhesive (1000 pack) | Brady | BR-10x5-1000 | Amazon | https://www.amazon.com/dp/B07YJHFKCD | 1 | 32.00 | 32.00 | 2 days | Chip ID labels
Chips + consumables | Opentrons Flex 8-channel tip rack 96 x 10 packs | Opentrons | OT-TIP-200-10 | Opentrons | https://shop.opentrons.com/opentrons-200ul-filter-tips/ | 1 | 180.00 | 180.00 | 1 week | Starter tip stock; operational BOM for sustaining
PCB + electronics | ESP32-S3-WROOM-1-N8R8 module | Espressif | ESP32-S3-WROOM-1-N8R8 | Digikey | https://www.digikey.com/en/products/detail/espressif-systems/ESP32-S3-WROOM-1-N8R8/16162642 | 1 | 4.50 | 4.50 | 1 week | Main MCU
PCB + electronics | LM2596S-5.0 buck regulator TO-263-5 | TI | LM2596SX-5.0/NOPB | Digikey | https://www.digikey.com/en/products/detail/texas-instruments/LM2596SX-5-0-NOPB/3494243 | 1 | 8.20 | 8.20 | 1 week | 5 V rail
PCB + electronics | AMS1117-3.3 LDO SOT-223 | AMS | AMS1117-3.3 | LCSC | https://www.lcsc.com/product-detail/Linear-Voltage-Regulators-LDO_Advanced-Monolithic-Systems-AMS1117-3-3_C6186.html | 1 | 0.12 | 0.12 | 3 weeks | 3.3 V rail
PCB + electronics | CH340N USB-UART bridge SOP-8 | WCH | CH340N | LCSC | https://www.lcsc.com/product-detail/USB-ICs_WCH-CH340N_C506813.html | 1 | 0.50 | 0.50 | 3 weeks | Fallback UART bootloader
PCB + electronics | DC barrel jack 2.1x5.5 mm through-hole | CUI | PJ-102A | Digikey | https://www.digikey.com/en/products/detail/cui-inc/PJ-102A/408448 | 1 | 1.10 | 1.10 | 1 week | 24 V power input
PCB + electronics | 5.08 mm pitch screw terminal 2-pin (10 pack) | On Shore | ED2609 | Digikey | https://www.digikey.com/en/products/detail/on-shore-technology-inc/ED2609/2794604 | 1 | 8.50 | 8.50 | 1 week | J3-J5 heater/fan/solenoid
PCB + electronics | JST-PH 3-pin header + cable kit | JST | B3B-PH-K-S | Digikey | https://www.digikey.com/en/products/detail/jst-sales-america-inc/B3B-PH-K-S/926612 | 3 | 0.55 | 1.65 | 1 week | Sensor connectors
PCB + electronics | JST-PH 4-pin header + cable kit | JST | B4B-PH-K-S | Digikey | https://www.digikey.com/en/products/detail/jst-sales-america-inc/B4B-PH-K-S/926613 | 2 | 0.60 | 1.20 | 1 week | I2C sensor
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

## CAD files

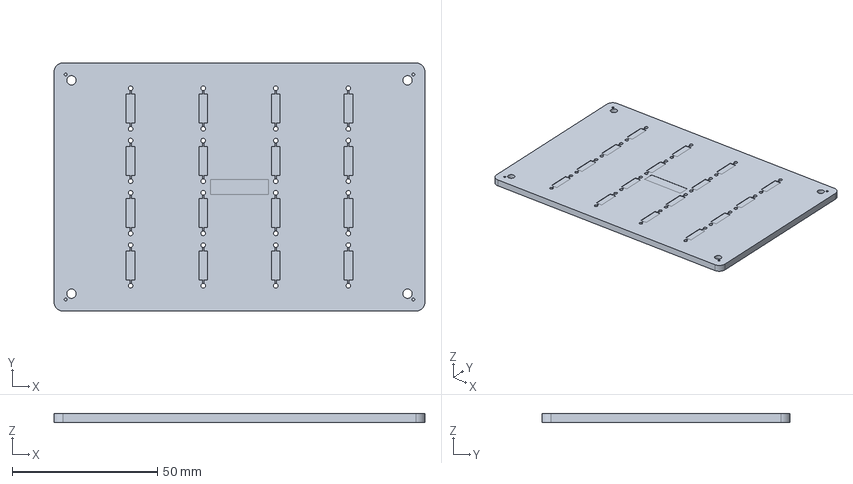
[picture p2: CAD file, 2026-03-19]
output/microfluidic_chip_16ch_channel_plate.stp
127.8 x 85.5 x 3.00 mm

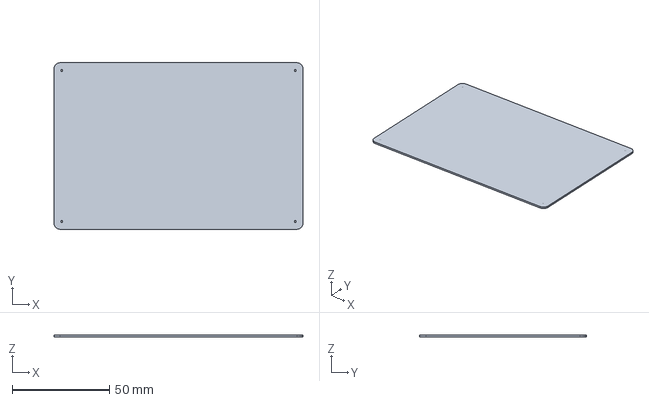
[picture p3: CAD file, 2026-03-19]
output/microfluidic_chip_16ch_cover_plate.stp
127.8 x 85.5 x 1.00 mm

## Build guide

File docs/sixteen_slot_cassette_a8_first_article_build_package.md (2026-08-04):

# 16-Slot Cassette A8 First-Article Build Package

Ticket: T-E0187ED3

This A8 package consolidates A0-A7 into the first practical build package for the LaminarForge 16-slot AAV cassette. It defines what can be built now, what must be generated or selected before vendor RFQ, how the first article should be assembled, and which acceptance gates block cells or AAV.

This is not a final vendor drawing set, sterile-barrier validation, biological protocol, AAV containment claim, or live-cell release criterion. It is a first-article engineering package for a dry reusable cassette/dock stack plus a disposable one-condition fluid path.

The active first-build architecture is the full 16-slot, 4 x 4 A0 cassette.
`docs/standard_footprint_aav_condition_module_a0.md` is a supplemental compact
module and local-coupon study only; it does not supersede this package or close
any 16-slot first-article gate.

## Package Status

| Lane | Status | Meaning |
| --- | --- | --- |
| Internal CAD fit-check package | Implemented draft | The active Rust CAD bin consumes the shared A0 contract and exports seven STL fit-check files. |
| True B-rep STEP package | Implemented draft | `sixteen_slot_cassette_first_article_step` exports six custom-part STEP drafts plus one stackup reference from the same A0 contract. These are not released manufacturing definitions. |
| Mechanical RFQ package | Blocked by drawings | D0-D9 drawings, inspection tables, selected hardware/connector details, and release review are still required. STEP draft availability does not make the package quote-ready. |
| Disposable fluid-path package | Architecture ready, SKUs open | A6 defines topology and port roles, but final tubing, connectors, pump interface, and harness vendor are not selected. |
| No-cell validation package | Layout mockup only; functional fixture blocked | `sixteen_slot_cassette_no_cell_validation_fixture` exports dry placement/envelope geometry. Its current tokens are solid, the dead-volume dye station is absent, and no characterized resistance articles or measurement hardware exist. It cannot execute or pass A7. |
| Media-only planning | Blocked until A7 gates pass | No-cell fit, leak, flow, bubble, dye recovery, and waste tests must pass first. |
| Live-cell/AAV work | Blocked | Requires A7 no-cell pass, media-only/aseptic evidence, safety/IBC workflow, and material compatibility data. |

## Controlling Inputs

| Input | A8 use |
| --- | --- |
| `docs/sixteen_slot_cassette_a0_interface_spec.md` | Controls slot map, dimensions, datums, one-condition semantics, dry structural policy, and downstream contracts. |
| `src/sixteen_slot_cassette_a0.rs` | Machine-readable mechanical contract consumed by both the STL fit-check and STEP draft generators. |
| `docs/sixteen_slot_cassette_a1_carrier_spec.md` | Controls carrier pocket, datum, drain, label, material, and handling assumptions. |
| `docs/sixteen_slot_cassette_a2_lid_clamp_spec.md` | Controls lid/clamp, imaging windows, captive fasteners, torque sequence, and stiffness requirements. |
| `docs/sixteen_slot_cassette_a3_gasket_spec.md` | Controls gasket material candidates, 2.40 mm cross-section, 25% target squeeze, grooves, hard stops, and leak/burst/reconnection logic. |
| `docs/sixteen_slot_cassette_a4_dfm_spec.md` | Controls manufacturing process, material, tolerance, finish, flatness, inspection, and RFQ requirements. |
| `src/bin/sixteen_slot_cassette_incubator_first_article.rs` | Active A5 integrated CAD generator and export source. |
| `docs/sixteen_slot_cassette_a6_disposable_fluid_path_spec.md` | Controls disposable one-condition single-pass harness, G/M/W port roles, prime/debubble path, waste path, and run record. |
| `docs/sixteen_slot_cassette_a7_no_cell_validation_fixture_spec.md` | Controls no-cell fixture architecture, test sequence, acceptance gates, and blockers before biology. |
| `docs/sixteen_slot_cassette_no_cell_bench_validation_protocol.md` | Controls physical execution order, samples, equipment readiness, measurement decisions, acceptance, and failure response. |
| `docs/sixteen_slot_cassette_no_cell_bench_validation_data_sheets.md` | Provides the controlled blank run record, raw-data tables, deviation form, and independent release matrix. |
| `docs/sixteen_slot_cassette_hp0_hp2_readiness_checklist.md` | Assigns HP-0 through HP-2 owners, evidence packages, dependencies, acquisition gaps, and gate-closing actions. |

## Locked Build Decisions

- First build format: 16 slots in a 4 x 4 cassette.
- Architecture authority: the active 16-slot A0 interface contract; compact
  standard-footprint work is supplemental risk retirement only.
- Experimental unit: one cassette equals one AAV capsid/promoter/payload/dose/timing/media condition.
- Slot role: cell-type and technical readouts under the same exposure, not separate AAV candidates.
- Active CAD bin: `sixteen_slot_cassette_incubator_first_article`.
- Reusable structural stack: carrier, lid/clamp, dock plate, service bulkhead test block, window placeholder, gasket witness coupon.
- Wetted path: disposable commercial tubing, connectors, reservoirs, filters, and pump-contact tubing.
- Flow mode: one-condition pressure-limited single-pass flow.
- Recirculation: deferred.
- CO2 incubation: deferred.
- Older 4 x 5 / 20-position CAD: reference only until explicitly ported to the 16-slot first-article geometry and A6 port map.

Locked mechanical values consumed by both generators:

| Interface | Base-body or nominal value | True overall or functional value |
| --- | --- | --- |
| Chip layout | 24.00 x 24.00 mm gutter; 151.76 x 109.48 mm pitch; 583.04 x 413.92 mm array | Centers X = +/-227.64, +/-75.88 mm; Y = +/-164.22, +/-54.74 mm |
| Carrier | 699.04 x 541.92 x 24.00 mm | 699.04 x 541.92 x 31.35 mm |
| Lid/clamp | 717.04 x 559.92 x 10.00 mm | 717.04 x 559.92 x 11.60 mm |
| Lid structure / chip clearance | 4.00 mm continuous underside seal skin plus 6.00 mm upper frame | Upper-only 635.04 x 457.92 mm lightening relief; sixteen 130.16 x 87.88 x 0.50 mm chip-top reliefs; 2.20 mm groove floor |
| Window | 667.04 x 489.92 x 3.00 mm | 667.04 x 489.92 x 4.80 mm |
| Dock | 869.04 x 691.92 x 22.00 mm | 869.04 x 691.92 x 40.00 mm |
| Bulkhead | 789.04 x 34.00 x 76.00 mm | 789.04 x 60.00 x 76.00 mm |
| Seal stack | Per-slot outer/inner 145.76 x 103.48 / 129.76 x 87.48 mm; perimeter outer/inner 629.04 x 459.92 / 605.04 x 435.92 mm | Both lands and all stops are 7.35 mm high and meet the lid underside; 6.00 mm inter-land gap; 1.80 x 3.20 mm lid grooves for a 2.40 mm gasket at 25% nominal squeeze |
| Hard stops / service relief | Nine 4.00 mm-diameter internal stops at the 3 x 3 inter-slot gap intersections; 4.00 mm-wide perimeter stops in the 5.00 mm seal-to-gutter web | No stop intersects a seal; 7.00 mm-high side reliefs remain below the 7.35 mm closure plane |
| Gutter / drain | 651.04 x 481.92 mm outer; 639.04 x 469.92 mm inner; 6.00 mm wide x 3.00 mm deep; 5.00 mm web | Drain diameter 8.00 mm at (315.52, -254.96, 10.00) mm, length 40.00 mm along Y |
| Fasteners / datums | Side X = +/-332.52 mm at slot-center Y; front/rear Y = +/-247.96 mm at slot-center X; all 16 carrier pilot receivers are 3.30 mm | D1-D4 at X = +/-335.52 mm, Y = +/-204.96 mm; only D1 round and D2 relieved locate. D1/D2 use replaceable lid-seated pins (5.80 x 7.35 mm CAD surrogate); D3/D4 have no pins. |
| Identity / sensor | Global 96.00 x 12.00 mm barcode land at (-271.52, -263.96) mm and 118.00 x 10.00 mm text land at (-159.52, -263.96) mm; per-slot labels outside gutter | Front lands clear the receiver row; bulkhead sensor/backplane cut center X = 320.00 mm |

Locked dock interfaces:

| Dock interface | A0 geometry | Build / inspection meaning |
| --- | --- | --- |
| Support and recesses | Datum-A support plane at local Z = +11.00; sixteen 137.76 x 95.48 mm recesses, 5.50 mm deep, at the slot centers | Inspect every recess floor at local Z = +5.50 and verify the carrier seats directly on datum A. |
| Registration | Rear 743.04 x 16.00 x 18.00 rail centered at Y = 278.96 mm; left 16.00 x 587.92 x 18.00 rail centered at X = -357.52 mm; front 743.04 x 10.00 x 10.00 lip centered at Y = -275.96 mm | Preserve the nominal rear/left/front carrier contacts; do not add an unrecorded spacer or offset. |
| Through-deck openings | Five 657.04 x 8.00 mm air bypass cuts at Y = -218.96, -109.48, 0.00, 109.48, 218.96 mm; front drain 799.04 x 10.00 mm at Y = -307.96 mm; right drain 10.00 x 615.92 mm at X = 392.52 mm; visibility opening 58.00 x 38.00 mm at (376.52, -287.96) mm | All cutters are 24.00 mm high through the 22.00 mm base deck. Their XY locations are locked. |
| Top-side lands | Sixteen 24.00 x 10.00 x 3.00 position-token lands; four solid 48.00 x 32.00 x 8.00 logger reservation lands; two 160.00 x 20.00 x 7.00 robot-lift lands; four 32.00 mm-diameter x 3.00 leveling lands | These are additive support/reservation geometry, not pockets, drains, or proof of sensing hardware. |
| Drain bridges | The front lip bridges part of the visibility cut; the two right logger lands bridge the right drain; front-left, front-right, and rear-right leveling lands bridge the named drain openings beneath them | The base-body region below datum A remains void and the additive land above is solid. Inspect both clear spans and bridge sections; do not describe the fit-check as a continuous gutter or validated sump. |
| Mounting | Six 5.40 mm through holes at X = +/-412.52 mm, Y = +/-323.96 mm plus X = 0.00 mm, Y = +/-323.96 mm | Freeze final M5 hardware and tolerances in D5. |

## Build Command And Generated Outputs

Run from the `laminarforge-cad` repo using the MCP build tool:

```text
mcp__agentic-mcp__laminarforge_build
repo: laminarforge-cad
action: run
bin: sixteen_slot_cassette_incubator_first_article
```

The fit-check command is defined to export the following seven STL files. Regenerate them for current-build evidence; historical A8 output does not substitute for a release manifest tied to the current A0 contract.

| Output | Role | A8 disposition |
| --- | --- | --- |
| `output/sixteen_slot_cassette_lower_carrier.stl` | Lower carrier fit-check model | Internal fit-check only; matching STEP draft exists, but D1 still controls RFQ release. |
| `output/sixteen_slot_cassette_lid_clamp.stl` | Lid/clamp fit-check model | Internal fit-check only; needs final captive hardware and drawing notes. |
| `output/sixteen_slot_cassette_window_placeholder.stl` | Retained window placeholder | Internal fit-check only; window material and sheet drawing remain open. |
| `output/sixteen_slot_cassette_gasket_witness_coupon.stl` | Gasket compression/leak witness coupon | Internal fit-check only; coupon drawing must duplicate final material/finish/groove notes. |
| `output/sixteen_slot_incubator_dock_plate.stl` | Dry dock plate with segmented through-deck openings and solid logger reservation lands | Internal fit-check only; drainage and incubation control are not validated by this part. |
| `output/sixteen_slot_service_bulkhead_test_block.stl` | Dry service bulkhead placeholder | Internal fit-check only; bought connector cutouts are not finalized. |
| `output/sixteen_slot_cassette_incubator_first_article_assembly.stl` | Combined assembly view | Assembly review only; not a manufacturing source. |

The `output/` directory is intentionally ignored by git. Regenerate these files from source instead of committing generated STL artifacts.

Run the STEP draft through the same MCP tool with `action: run`,
`bin: sixteen_slot_cassette_first_article_step`, and `features: ["step"]`.
The runner supplies the required OpenCascade CMake policy environment. The
underlying exporter invocation is recorded in the run artifact for
reproducibility but is not the operator workflow.

It creates seven true B-rep draft files under `output/rfq/` and fails if any
required file is missing. Re-import all outputs in a separate OpenCascade
verifier pass and require one closed solid per standalone part plus a readable
stackup reference. Run `sixteen_slot_cassette_step_verify` with the same `step` feature
immediately after export; it performs that re-import, solid-count, topology, and
A0-envelope gate. Both verifiers also probe dock recess floors, clear
through-deck spans, and representative void-below/solid-above bridge sections.
The STEP and STL lid builders use parity-equivalent
construction and subtract the 1.80 x 3.20 mm underside grooves last. D0-D9
drawings still block RFQ release.

## Custom Part Package

| Part | Current draft source | Preferred first-article process | Material direction | Critical notes |
| --- | --- | --- | --- | --- |
| Lower carrier | `output/rfq/sixteen_slot_cassette_lower_carrier.step` plus fit-check STL | CNC machined plate after D1 release | 6061-T651/T6 aluminum, clear Type II anodize option | Dry structural part; preserve A0 datums, 16 pockets, 7.35 mm lands/stops, 3.30 mm receiver pilots, drain, labels, handling lands, and 7.00 mm service reliefs. |
| Lid/clamp | `output/rfq/sixteen_slot_cassette_lid_clamp.step` plus fit-check STL | CNC machined or waterjet rough + secondary machining after D2 release | 6061-T6/T651 aluminum or stainless alternate | Must use controlled compression, captive M4 hardware assumption, imaging keepouts, and torque sequence. |
| Window placeholder | `output/rfq/sixteen_slot_cassette_window_placeholder.step` plus fit-check STL | CNC/laser-cut sheet after D3 release | Polycarbonate for fit-check; borosilicate/glass if imaging requires | Mechanically retained; adhesive-only retention is not the baseline. |
| Gasket witness coupon | `output/rfq/sixteen_slot_cassette_gasket_witness_coupon.step` plus fit-check STL | CNC machined coupon after D4 release | Same seal-band material/finish assumptions as final stack | Must duplicate gasket groove, stop, finish, and hardware strategy for evidence. |
| Dock plate | `output/rfq/sixteen_slot_incubator_dock_plate.step` plus fit-check STL | CNC machined plate after D5 release | 6061-T651/T6 aluminum or stainless alternate | Dry support with locked segmented through-deck openings and solid logger/leveling/handling lands. D5 must section every bridge and dimension every clear span. |
| Service bulkhead test block | `output/rfq/sixteen_slot_service_bulkhead_test_block.step` plus fit-check STL | CNC machined dry block after D6 and connector selection | Aluminum or polycarbonate dry structure | Placeholder holes are not connector drawings and not sterile ports. |

## Bought Component BOM Assumptions

These are first RFQ/test assumptions, not final SKUs.

| Function | Starting assumption | Owner / closeout |
| --- | --- | --- |
| Lid fasteners | Stainless M4 x 0.7 captive panel screws with positive-drive heads | A2/A4/vendor to finalize length, head style, retainers, and torque. |
| Carrier receivers | Sixteen locked 3.30 mm M4 tap-drill/pilot placeholders, finished with stainless threaded inserts, nut plates, or replaceable threaded receiver hardware | A4/vendor to select the final thread/insert SKU; post-install flatness inspection required. |
| Datum pins | Replaceable 6 mm stainless ground dowel family; active CAD surrogate is 5.80 mm diameter x 7.35 mm long in 6.00 mm x 4.00 mm D1/D2 lid seats | A1/A4 to finalize pin SKU and bore/seat tolerances while preserving D1 round, D2 relieved, and D3/D4 no-pin clearance/witness roles. |
| Gasket | Platinum-cured silicone 50-60A first quote; high-purity EPDM 60-70A alternate | A3/A4/vendor to finalize compound, tolerance, compression set, and compatibility. |
| Window | Optically clear polycarbonate for fit-check; borosilicate/glass alternate | Imaging/material review to select final. |
| Labels | Humidity/IPA-wipe compatible 2D code plus human-readable label stock | Build package/vendor to select and test condensation survival. |
| Tubing | Compare weldable TPE/C-Flex-style route and silicone/peristaltic route if budget allows | A6/pump owner/material review to select. |
| Connectors | Bought aseptic connectors or sterile tube welding for live-use planning; low-dead-volume connectors for no-cell only | A6/RFQ to select final connector family and panel cutouts. |
| Waste | Sealed waste bag or bottle with anti-backflow/siphon strategy | A6/A7 validation to prove. |
| Sensors | Pressure sensors at common upstream, four rows, and waste/backpressure; optional flow/bubble sensors | A7 fixture owner to select. |
| Collection | Sixteen vial nests or gravimetric collection positions | A7 fixture owner to select. |
| Dye/leak witness | Nonhazardous visible dye, wicking paper or clear leak tray | A7 validation to select and record. |

## Vendor RFQ Deliverables Still Required

The package is not vendor-ready until these are created:

- Regenerated and reviewed STEP draft manifest tied to the release commit; the STEP exporter exists, but its outputs remain draft support geometry until paired with drawings.
- 2D drawing for each custom part with material, finish, tolerances, flatness, surface finish, datum scheme, inspection table, and no-biological-claim notes.
- Stackup drawing showing chip, carrier, gasket, lid/clamp, window, hard stops, and compression witness locations.
- Hardware table with fastener, insert, dowel, washer/retainer, and torque assumptions.
- Gasket drawing or supplier print with cross-section, compound, splice/join strategy, compression target, and lot traceability.
- Label drawing with global cassette/condition ID land, per-slot labels, slot-1 orientation, and barcode size.
- Connector panel drawings using selected bought connector datasheets, not placeholder hole diameters.
- D5 dock sections that dimension every unbridged drain/visibility span and show
  the front-lip, logger-land, and leveling-land bridges without moving the A0
  opening coordinates.
- No-cell validation fixture drawing or sourced fixture plan for pressure, bubble, flow, dye, waste, and repeat-cycle gates.
- Vendor note that the quote is a mechanical no-cell first article only and makes no sterile, clinical, live-cell, AAV containment, or biological release claim.

## Assembly Order

Use this order for the first physical build. Do not skip metrology gates because later no-cell tests can pass while hidden damage or overcompression remains.

1. Regenerate STL outputs from the active CAD bin and verify the seven expected files exist.
2. Regenerate the implemented true B-rep STEP drafts and create/review D0-D9 drawings; without the drawings, keep the package internal only.
3. Inspect machined carrier, lid, dock, bulkhead, window, and coupon before installing hardware.
4. Verify carrier dimensions: pocket array, datum bores, rear/left/front datum edges, 7.35 mm gasket lands and hard stops, 3.30 mm fastener pilots, 7.00 mm service reliefs, drain, label lands, and optical openings.
5. Verify lid dimensions: 4.00 mm sealing skin, upper-only relief, 0.50 mm chip
   reliefs, 2.20 mm groove floor, outside-gutter fastener holes, D1/D2 pin seats,
   D3/D4 no-pin policy, alignment ears, 1.80 x 3.20 mm underside gasket grooves,
   window retention, and torque sequence marks.
6. Verify dock dimensions: direct datum-A support plane; sixteen exact recess
   floors; rear/left rail inner faces; front lip; clear spans of the front,
   right, visibility, and air-bypass through-cuts; void-below/solid-above bridge
   sections; solid logger reservation lands; carrier support flatness; and
   robot/manual handling keepouts.
7. Install threaded receivers, captive hardware, dowels, and labels only after pre-install metrology passes.
8. Recheck flatness, burrs, datum fits, and label placement after hardware installation.
9. Install surrogate Rev C chips or gauge chips into all 16 pockets and confirm 16/16 seating without forcing.
10. Install gasket or coupon material using the A3 process and verify witness shims.
11. Install retained window placeholder without point-loading or blocking view openings.
12. Close lid/clamp using the A2 paired cross-pattern torque sequence and record driver setting, hardware lot, and witness results.
13. Seat the carrier directly on datum A, contact the nominal rear/left/front edges against the rail inner faces and front lip, and confirm the dock does not twist the carrier or hide drain/witness paths.
14. Connect the A6 disposable harness for dry topology inspection.
15. Run the A7 no-cell sequence before any media-only, live-cell, or AAV planning.

## QA And Inspection Checklist

| Area | Required evidence |
| --- | --- |
| Slot map | 4 x 4 row-major S01-S16 confirmed against A0. |
| Dimensions | Carrier, lid, dock, bulkhead, window, and coupon measured against drawings or CAD fit-check targets. |
| Datums | Direct datum-A seating, nominal rear/left/front edge contact, and D1/D2 locator behavior verified without overconstraint. |
| Pocket fit | 16/16 surrogate chips seat; no burrs, binding, or pocket-floor debris. |
| Gasket compression | 20-30% guard band with 25% target; 1.68-1.92 mm compressed height if using 2.40 mm nominal gasket; land/stop faces contact the lid underside and nominal height is set by the 1.80 mm groove cavity. |
| Fasteners | Captive hardware retained, torque sequence marked, centers remain outside the gutter, and all 3.30 mm carrier pilots/final receiver installations are inspected. |
| Imaging | 16 view openings and carrier optical windows unobstructed by lid, gasket, labels, tubing, or window retention. |
| Drain/leak witness | Carrier gutter/drain and dock clear spans are visible when docked; front-lip, logger-land, and leveling-land bridges match D5 sections; no gravity-flow or condensate-capacity claim is made until no-cell testing passes. |
| Fluid path | G/M/W ports, R1-R4 branches, S01-S16 pigtails, waste paths, caps, and labels traceable to run record. |
| Labels | Cassette ID, condition ID, slot map revision, harness ID, and waste ID readable/scannable after assembly. |
| Cleaning | No residue, sharp chips, blasting media, corrosion, label lift, or dye-trapping crevices after cleaning trial. |
| Documentation | Photos, measurements, material lots, hardware lots, gasket lots, harness lots, and pass/fail gates recorded. |

## No-Cell Acceptance Gates

A8 adopts the A7 acceptance gates as build-release gates:

| Gate | Minimum pass condition |
| --- | --- |
| Fit and datum | 16/16 surrogate chips seat; cassette registers to rear/left datums; lid aligns without forcing. |
| Compression | A3 witness target met, nominally 20-30% squeeze with 25% target. |
| Harness map | Every port, row, slot, and waste path traceable to the run record. |
| Prime | 16/16 paths prime with no visible bubble at chip inlet witnesses. |
| Bubble challenge | Calibrated, preapproved bubble stimulus clears to W1/W3 within the frozen clearing volume/time without reaching chip inlet witnesses; unset stimulus/limits fail. |
| Leak | Installed system has no visible dye leak and guard-banded decay `100 x (P0 - P10) / P0 <= 5%` at 1.5x maximum operating pressure, using no active makeup, at least 661 s acquisition, P0 mean over t = 0-60 s, and P10 mean over t = 600-660 s; representative isolated gasket loop also passes A3 qualification. |
| Flow balance | Row and slot CV are each <=10% for the characterized nominal surrogate set; pressure drift is within +/-5% after stabilization. |
| Restriction detection | Independently characterized nominal, low, high, blocked, and bypass coupons remain in band and produce signatures separated by at least three combined standard uncertainties. |
| Dead volume | Recovery reconciles within +/-10%; unrecovered volume is below the A6 target with no discretionary waiver. |
| Waste safety | No backflow, siphon, or uncontrolled overflow into cassette or bench. |
| Repeatability | Cycles 1, 5, 10, and 25 pass the same required gates. |

## First-Article Run Record

Every first-article build/run should create a searchable artifact with:

- Ticket ID and artifact ID.
- Commit hash and CAD bin used.
- MCP build/run records, seven-output STL confirmation, seven-output STEP
  confirmation, STL probe report, and separate STEP re-import/solid-count
  report.
- Cassette serial/revision and part revision set.
- Carrier/lid/dock/bulkhead/window/coupon material, finish, supplier, and inspection reports.
- Fastener, insert, dowel, gasket, window, label, tubing, connector, reservoir, and waste lots.
- Slot map revision and G/M/W port map revision.
- Torque driver setting and paired sequence used.
- Compression witness measurements.
- Harness topology photos and scan results.
- A7 prime, bubble, leak, flow, restriction, dye recovery, waste, and repeat-cycle results.
- Deviations, rejected parts, corrective actions, and retest status.

## Open Decisions Blocking RFQ Or Biology

| Decision | Blocks | Required owner action |
| --- | --- | --- |
| D0-D9 drawings and STEP release manifest | Vendor RFQ | The true B-rep STEP exporter is implemented; create the drawings, inspection tables, release manifest, and review record. |
| Final Rev C chip lot dimensions | Carrier drawing release | Measure chip lot and resolve pocket target versus 1.20 mm CAD fit-check clearance. |
| Final pin/bore production detail | Carrier/lid drawing release | Select pin SKU, D2 relief detail, and bore tolerances while preserving the locked D1-round/D2-relieved roles. |
| Final hardware and torque | Physical build release | Select captive M4 hardware, final thread/insert SKU, insert process, washers/retainers, and torque-to-stop value while preserving the locked centers and 3.30 mm carrier pilots. |
| Final gasket compound and supplier | Physical build release | Select silicone/EPDM compound, cross-section tolerance, splice strategy, and coupon plan; the 1.80 x 3.20 mm lid groove and 7.35 mm land/stop stack are already fixed. |
| Final seal-band finish/coating plan | Vendor RFQ | Decide masked anodize, post-machining, or as-machined seal bands. |
| Final window material | Imaging and cleaning tests | Choose polycarbonate or glass and define retention/cleaning compatibility. |
| Final connector and tubing SKUs | Fluid-path RFQ and validation fixture | Select bought connector family, tubing OD/ID, weldability, pressure rating, and panel cutouts. |
| Pump/pressure-control interface | A7 validation | Select pressure-limited pump/control mode and sensor range. |
| Functional A7 fixture, drawings, and sourced hardware | No-cell validation | Replace solid layout tokens with flow-through surrogate/restriction coupons, add the missing dead-volume dye station, freeze bubble/waste stimuli and uncertainties, then build/quote pressure, collection, leak, dye, and waste modules with selected measurement hardware. |
| Media-only aseptic workflow | Live-cell planning | Prove no-cell gates, then media-only/aseptic transfer evidence. |
| IBC/safety workflow for AAV | AAV work | Define containment, waste handling, decontamination, documentation, and approvals. |

## Explicit Blockers

These are not negotiable in the first article:

- Do not send STL files alone as a vendor manufacturing definition.
- Do not treat the carrier, lid, dock, bulkhead, or gasket as a validated sterile wetted path.
- Do not route multiple AAV candidates through one cassette.
- Do not use the 16 slots as separate AAV lanes.
- Do not introduce recirculation until single-pass recovery, sterility, and carryover evidence exists.
- Do not run cells before A7 no-cell gates pass.
- Do not run AAV before media-only/aseptic evidence and safety/IBC workflow exist.
- Do not use older 4 x 5 / 20-position fixtures as proof for the 16-slot cassette.
- Do not silently relocate dock openings or erase additive bridges to make the
  fit-check appear to have continuous drainage; either validate the locked A0
  topology or revise A0 explicitly.

## Next Tickets

Recommended next work after A8:

1. Complete the A9 D0-D9 drawing and release-manifest package. The six-part plus stackup STEP draft exporter is already implemented; see `docs/sixteen_slot_cassette_a9_step_drawing_export_plan.md`.
2. A10 16-slot A7 validation fixture iteration into STEP/drawings or sourced bench fixture package.
3. A11 bought-component downselect for tubing, connectors, pump/pressure-control, sensors, labels, and collection hardware.
4. A12 RFQ packet draft with vendor questions, drawing notes, inspection table, and quote options.

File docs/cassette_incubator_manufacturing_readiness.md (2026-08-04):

# 16-Slot Cassette/Incubator Manufacturing Readiness Package

This is the first manufacturable direction for the LaminarForge cell-culture equipment stack. It narrows the work from broad equipment concepts to one buildable subsystem: a 16-slot closed cassette carrier that can dock into an incubated module/rack.

## Current Decision

Use a 16-slot, 4 x 4 cassette/module as the first hardware anchor. This is now the committed first-build format for the AAV cassette work.

One cassette remains one AAV capsid/promoter/payload/dose/timing/media
condition. The 16 slots are same-condition readouts, not separate AAV
candidates. This package is mechanical manufacturing readiness only; it does
not establish sterility, containment, live-cell readiness, or biological
validity.

The immediate work is the cassette first article: reusable lower carrier, reusable lid/clamp, gasket/witness system, disposable sterile tubing harness assumptions, barcode/condition ID, no-cell validation fixture, and dock/module interfaces reserved for later controlled incubation. Do not spend the next build cycle on CO2 incubator control; design the cassette so it can dock into a cassette-level controlled module later.

The shared mechanical/interface baseline for downstream agents is
`docs/sixteen_slot_cassette_a0_interface_spec.md`. The compact
`docs/standard_footprint_aav_condition_module_a0.md` direction is a supplemental
module/local-coupon study, not a replacement for the active 16-slot first build.

Both the STL fit-check and true B-rep STEP draft generators now consume `src/sixteen_slot_cassette_a0.rs`. The contract corrected the predecessor geometry's overlapping per-slot seal loops, unequal seal-land heights, undersized margins, gutter/label conflicts, corner-stop layout, and fasteners inside the gutter. Both lid builders complete additive geometry before subtracting the shared underside grooves so STEP and STL remain parity-equivalent. Use the following nomenclature and values in RFQs and drawings:

| Interface | Base-body or nominal dimensions | True overall or functional dimensions |
| --- | --- | --- |
| Chip layout | 24.00 x 24.00 mm gutter; 151.76 x 109.48 mm pitch; 583.04 x 413.92 mm array | Centers X = +/-227.64, +/-75.88 mm; Y = +/-164.22, +/-54.74 mm |
| Carrier | 699.04 x 541.92 x 24.00 mm | 699.04 x 541.92 x 31.35 mm |
| Lid/clamp | 717.04 x 559.92 x 10.00 mm | 717.04 x 559.92 x 11.60 mm |
| Window | 667.04 x 489.92 x 3.00 mm | 667.04 x 489.92 x 4.80 mm |
| Dock | 869.04 x 691.92 x 22.00 mm | 869.04 x 691.92 x 40.00 mm |
| Dock support / recesses | Datum-A support plane at local Z = +11.00; sixteen 137.76 x 95.48 mm recesses at slot centers | 5.50 mm recess depth; exact floor local Z = +5.50 |
| Dock through openings | Five 657.04 x 8.00 mm air bypasses; 799.04 x 10.00 mm front drain; 10.00 x 615.92 mm right drain; 58.00 x 38.00 mm visibility opening | All use 24.00 mm-high cutters through the 22.00 mm deck at the locked A0 coordinates |
| Dock top-side lands / bridges | Sixteen position-token lands; four solid 48.00 x 32.00 x 8.00 logger reservation lands; two robot-lift lands; four 32.00 mm-diameter leveling lands | Additive lands deliberately bridge portions of the visibility, front-drain, and right-drain openings while leaving base-body void below datum A |
| Service bulkhead | 789.04 x 34.00 x 76.00 mm | 789.04 x 60.00 x 76.00 mm |
| Per-slot seal lands | 145.76 x 103.48 mm outer; 129.76 x 87.48 mm inner; 8.00 mm width | 7.35 mm height; 6.00 mm clear gap; 16 independent, nonoverlapping loops; land face meets lid underside |
| Perimeter seal land | 629.04 x 459.92 mm outer; 605.04 x 435.92 mm inner; 12.00 mm width | 7.35 mm height on the common lid underside closure plane |
| Lid grooves / hard stops | 1.80 mm deep x 3.20 mm wide grooves for 2.40 mm gasket | Nine 4.00 mm-diameter inter-slot stops plus 4.00 mm-wide perimeter stops in the 5.00 mm web; all top at 7.35 mm and clear every seal |
| Leak gutter and drain | 651.04 x 481.92 mm outer; 639.04 x 469.92 mm inner; 6.00 mm width x 3.00 mm depth; 5.00 mm separating web | Drain diameter 8.00 mm, center (315.52, -254.96, 10.00) mm, length 40.00 mm along Y |

Datum A is the carrier bottom plane seated directly on the dock support plane;
the rear/left rail inner faces and front lip contact the nominal rear, left, and
front carrier edges. D1-D4 sit at X = +/-335.52 mm and Y = +/-204.96 mm, but
only D1 round and D2 relieved are functional locators. The 16 lid fasteners sit
outside the gutter at side X = +/-332.52 mm on the slot-center Y values and
front/rear Y = +/-247.96 mm on the slot-center X values. All 16 matching carrier
M4 tap-drill/pilot receiver placeholders are 3.30 mm; final thread/insert SKU
remains open. The global 96.00 x 12.00 mm barcode land at (-271.52, -263.96)
mm and 118.00 x 10.00 mm text land at (-159.52, -263.96) mm stay outside the
gutter and clear the front receiver row; per-slot labels also stay outside the
gutter. The 7.00 mm-high side service reliefs stay below closure, and the service
sensor/backplane cut stays centered at X = 320.00 mm.

The dock openings are not continuous gutter/sump claims. The front lip bridges
part of the visibility opening, both right-side logger reservation lands bridge
the right drain, and the front-left, front-right, and rear-right leveling lands
bridge the drain openings beneath them. The A0 generators intentionally retain
void below datum A and solid additive land above at these overlaps. D5 must show
each bridge in section and dimension the remaining clear spans; moving an
opening to hide the overlap requires an explicit A0 revision. No-cell drainage,
condensate capacity, and cleaning evidence remain required.

The repo contains two competing cassette directions:

| Direction | Status | Decision |
| --- | --- | --- |
| 20-chip cassette/shelf | Exists in `automated_media_exchange_cassette`, `cassette_storage_recovery_incubator_rack`, `sealed_culture_module`, and older chip-farm models. Good density concept, but too spread out for first manufacturing. | Defer. |
| 16-slot closed cassette | Exists across gasket install, attachment/settle, media exchange, evaporation balance, environmental mapping, and seeding validation fixtures. Better aligned with the user's remembered 16-slot board and easier to harden first. | Use as first build package baseline. |

## Fresh Research Check

Exa research was restored and run for this package. The design direction is supported by current organ-on-chip and incubator references:

| Source | Relevant finding | Design implication |
| --- | --- | --- |
| Minahan et al., modular reusable perfusion-ready MPS platform, PMC12914553 | A reusable acrylic cassette can clamp interchangeable elastomeric inserts, forming leak-tight channels without irreversible bonding; the platform emphasizes imaging access, sterilizable/reusable hardware, and parallel insert seeding before perfusion. | Keep the LaminarForge carrier reusable and structural; make the cell-contact/fluid-contact layer disposable or separately validated. Use screw/clamp compression and visible gasket witnesses rather than adhesive-only sealing. |
| Modular fluidic circuit board for parallelized cell culture, Microsystems & Nanoengineering | A standardized plug-and-play fluidic circuit board can operate multiple microfluidic building blocks and reduce the external tubing/footprint problem. It references standardized MFBB/FCB interface formats and 1.5 mm inlet grids. | Treat the cassette as a mechanical/fluidic interface board, not just a tray. Freeze port locations, datum scheme, and routing interface early. |
| AKITA scalable OOC/TEER platform, PMC11583584 | Standard 96-well/384-well plate layouts improve automation compatibility; TEER and automated liquid handling are integrated as repeatable readouts. | Preserve automation-compatible spacing where possible and reserve sensor/TEER/readout features in the cassette/dock stackup. |
| Baker humidity/condensation white paper | Common culture targets are 37 C, 5% CO2, and about 95% RH; poor RH feedback and condensation can drive evaporation, contamination, and irreproducibility, especially in small volumes. | The incubator module needs per-slot evaporation/RH evidence and condensation management before live-cell claims. |
| PHCbi incubator selection guide | Commercial incubators specify 0-20% CO2 control, temperature uniformity, RH behavior, access ports, stainless/copper alloy interiors, shelves, and decontamination options. | Use commercial incubator specs as benchmark targets and buy critical sensors/control elements rather than inventing all of them. |
| Thermo Fisher incubator care guide | Incubator placement, leveling, ventilation clearance, sterile distilled water, gas regulation, leak checks, and independent calibration are routine requirements. | Add leveling, independent logging/calibration, gas leak checks, and water-quality assumptions to the first-article test plan. |
| Parker O-Ring Handbook | O-ring/gland design is application-specific and requires material compatibility, pressure, temperature, tolerance, and failure-mode analysis. | Keep the fixed 2.40 mm gasket, 1.80 x 3.20 mm nominal lid groove, and 20-30% squeeze band; selected compound, dimensional tolerance, groove fill, and validation evidence still require vendor review. |

## Baseline CAD Evidence

The current repo has manufacturable-reference geometry, but not final production drawings.

| Model | Evidence from current CAD/build | Manufacturing relevance |
| --- | --- | --- |
| `sixteen_slot_cassette_incubator_first_article` plus `sixteen_slot_cassette_first_article_step` | The active generators share the machine-readable A0 contract and emit seven STL fit-check files plus seven true B-rep STEP drafts. | Controlling first-article mechanical source. STEP remains draft support geometry until D0-D9 drawings are released. |
| `closed_cassette_gasket_install_torque_compression_station` | Historical 4 x 4 fixture with torque stages, leak-test ports, and compression witnesses. Its pre-contract dimensions and seal layout do not control the first article. | Reference only for test-fixture ideas; do not copy its geometry into drawings. |
| `closed_cassette_cell_attachment_settle_uniformity_witness_station` | MCP build exports 13 STLs. Reports 4 x 4 no-flow slots on a 663 mm x 492 mm nest, timed perfusion gates, humidity witnesses, edge/center markers. | Best source for slot layout, attachment dwell, level/tilt, and imaging access requirements. |
| `closed_incubator_slot_to_slot_media_evaporation_balance_station` | MCP build exports 12 STLs. Reports 16 media surrogates, 16 RH logger pockets, 4 dewpoint references, 16 condensate witness lands, 16 matched humidity ports/restrictor coupons. | Best source for incubator rack slot-to-slot reproducibility requirements. |
| `closed_media_exchange_shear_pulse_carryover_validation_station` | MCP build exports 13 STLs. Reports 16 feed, 16 flush, and 16 harvest route legs, pressure/flow docks, bubble/dead-volume windows, and carryover wells. | Best source for fluid routing and per-slot media-exchange validation requirements. |
| `sealed_culture_module` | MCP build exports 5 STLs. Reports 892 mm x 788 mm footprint with gasketed lid frame, service bulkhead, and thermal plate interface. | Useful enclosure/docking concept, but it is based on the older 20-chip cassette geometry and must be resized around the 16-slot baseline. |

## Manufacturer-Ready Scope For First Quote

Do not quote the whole incubator/cell-culture machine yet. Quote the mechanical cassette and dock test article first.

### Custom Parts To Quote First

| Part | Starting CAD source | Preferred process | Material direction | Notes |
| --- | --- | --- | --- | --- |
| 16-slot cassette lower carrier | `output/rfq/sixteen_slot_cassette_lower_carrier.step` draft from the active A0 contract | CNC machining after D1 drawing release | 6061-T651/T6 aluminum, clear anodized, or alternate after material review | Structural carrier only. Keep wetted sterile path disposable or separately validated. |
| Cassette lid/clamp frame | `output/rfq/sixteen_slot_cassette_lid_clamp.step` draft | CNC machining or waterjet + secondary machining after D2 release | 6061-T651/T6 aluminum or stainless 304/316 | Needs controlled gasket compression, captive fasteners, and inspection window cutout. |
| Optical/imaging window insert | `output/rfq/sixteen_slot_cassette_window_placeholder.step` draft or controlled sheet drawing | Laser/CNC cut sheet after D3 release | Polycarbonate or borosilicate/glass depending imaging need | Must be mechanically retained; adhesive-only sealing is not enough for first article. |
| Gasket groove/witness coupon | `output/rfq/sixteen_slot_cassette_gasket_witness_coupon.step` draft | CNC machining after D4 release | Same seal-band material/finish as carrier plus selected gasket material | Use witness shims and compression coupons before trusting the real cassette. |
| Incubator slot dock plate | `output/rfq/sixteen_slot_incubator_dock_plate.step` draft | CNC machining or sheet metal + machined inserts after D5 release | 6061-T651/T6 aluminum or stainless 304 | Preserve the locked segmented through-deck openings, solid logger reservation lands, bridge sections, slot repeatability, and robot/finger access. |
| Service bulkhead test block | `output/rfq/sixteen_slot_service_bulkhead_test_block.step` draft | CNC machining or printed fit-check only after D6 release | Aluminum/PC for dry structure; commercial connectors for sterile/fluid boundary | Preserve the A6 G/M/W role map; bought connector data controls final cutouts. |

### Off-The-Shelf Parts To Select

| Function | Buy item class | Reason |
| --- | --- | --- |
| Fastening | Stainless M3/M4/M5 screws, dowel pins, heat-set/captive inserts where appropriate | Repeatable assembly and registration. |
| Seal | Silicone or EPDM gasket cord/sheet, selected after chemical/sterilization review | Gasket compression is a core risk. |
| Fluid transfer | Sterile disposable tubing, luer/dry-break/aseptic connectors, check valves | Avoid custom wetted printed/machined paths for first culture-facing prototype. |
| Incubator sensing | Independent temp/RH logger, external incubator-range 0-20% CO2 sensor/analyzer | Controller sensor alone is not validation evidence. |
| Slot monitoring | RH/dewpoint logger hardware mounted from the solid reservation lands; optional optical O2 spots/sensors later | Needed to prove slot-to-slot variability; active dock geometry does not contain logger pockets. |
| Thermal interface | Silicone heater pad or external thermal plate, thermal cutoff, insulation | Keep heaters serviceable and isolated from wet leaks. |
| Identification | Barcode/RFID labels/tags compatible with humidity/condensation | Run identity must survive incubation. |

## What Remains Before RFQ

The STL files remain fit-check only, and the implemented STEP files remain drafts. Drawings still block a vendor package. Remaining items:

- D0-D9 2D drawings with critical tolerances, inspection tables, and release index.
- Reviewed STEP/drawing manifest tied to the release commit.
- Final material callouts and surface finish.
- Selected gasket compound/vendor/tolerance and tested fastener torque-to-stop value. The 2.40 mm free height, 1.80 x 3.20 mm lid groove, 25% compression target, and 7.35 mm common land/stop/closure plane are already defined.
- Drawing implementation of the locked A/B/C datum scheme and D1-round/D2-relieved locator roles.
- Fluid connector family and panel cutout dimensions.
- Stackup drawing showing chip, gasket, lid, carrier, window, and clamp height.
- Leak-test pressure method and allowable deformation.
- Cleaning/sterilization assumptions for each material.
- DFM review for minimum wall thickness, tool reach, internal corners, and part warpage.
- D5 sections and inspection dimensions for every clear drain/visibility span
  and every front-lip, logger-land, and leveling-land bridge, without relocating
  the A0 opening coordinates.

## First Build Package Requirements

Before sending to a manufacturer, regenerate and review these implemented drafts from the 16-slot baseline and create their controlling drawings:

| Deliverable | Required content |
| --- | --- |
| `output/rfq/sixteen_slot_cassette_lower_carrier.step` | Implemented draft: 16 chip pockets, direct A/B/C datum interfaces, 7.35 mm gasket lands/stops, 3.30 mm receiver pilots, 7.00 mm service reliefs, gutter/drain, and labels. Requires D1. |
| `output/rfq/sixteen_slot_cassette_lid_clamp.step` | Implemented draft: imaging openings, 1.80 x 3.20 mm underside grooves, outside-gutter fastener pattern, and alignment features. Groove operation order is parity-equivalent to STL. Requires D2. |
| `output/rfq/sixteen_slot_cassette_window_placeholder.step` | Implemented retained-window draft with base thickness and raised witness/retention features. Requires D3 or controlled sheet drawing. |
| `output/rfq/sixteen_slot_incubator_dock_plate.step` | Implemented dock draft with exact recess floors, rails/lip, segmented through-deck openings, solid logger/handling/leveling lands, and intentional void-below/solid-above bridges. Requires D5 sections and no-cell drainage evidence. |
| `output/rfq/sixteen_slot_service_bulkhead_test_block.step` | Implemented dry receiver draft with the preserved A6 gas/media/waste map and sensor placeholder. Requires D6 and bought-connector data. |
| Drawing set | One PDF per machined part with dimensions, tolerances, material, finish, and inspection notes. |
| BOM | Custom parts, hardware, gasket, sensors, tubing/connectors, labels, and consumables. |
| Vendor notes | Prototype purpose, no biological validation claim, request for DFM feedback, and quote options by material/process. |

## Proposed First-Article Tolerances

These are starting engineering targets, not final release specs.

| Feature | Starting target |
| --- | --- |
| Chip pocket XY clearance | 0.5-0.8 mm per side until chip lot tolerance is measured. |
| Datum pin holes | Reamed or precision drilled after choosing pin diameter; avoid relying on printed-hole tolerance. |
| Gasket compression | Design around 20-30% squeeze with a nominal 25% witness target. |
| Flatness under cassette | Call out after material/process selection; do not assume large printed parts are flat enough. |
| Surface finish near gasket | Smooth machined finish; no layer lines on seal lands. |
| Internal corners | Add machineable radii; avoid square internal pockets unless EDM is intended. |
| Wet path | Disposable commercial tubing/connectors for first article. Structural parts should not be treated as validated wetted surfaces. |

## Incubator/Dock Control Targets

Use these as engineering targets for the cassette dock test article. They are not biological release claims.

| Control | First-article target |
| --- | --- |
| Temperature | 37 C nominal, mapped at all 16 slot positions and independently logged. Benchmark against commercial incubator uniformity expectations. |
| CO2 | 5% nominal for bicarbonate-buffered media, measured with an incubator-range 0-20% sensor/analyzer. |
| Humidity | High RH target with logged slot-to-slot evaporation; do not assume an open-loop water pan proves humidity control. |
| Condensation | No uncontrolled dripping onto cassette/chips. Test collection through the locked clear spans and around the intentional bridges; do not assume the fit-check geometry proves drainage. |
| Oxygen | Reserve sensor/coupon windows, but do not make O2-control claims until gas mixing and sensor calibration are designed. |
| Fluid exchange | Dye-only first: per-slot flow, carryover, bubble, dead-volume, and pressure-spike checks before live-cell use. |
| Sterility boundary | Closed/disposable fluid path first; structural cassette is not automatically a sterile wetted component. |

## Vendor Questions

Send these with the RFQ:

1. Can you machine the 699.04 x 541.92 x 24.00 mm base-body carrier flat enough for gasket compression without stress relief or post-machining warp?
2. What material/process gives the best first article: 6061-T6 clear anodized, stainless, polycarbonate, or another autoclavable plastic?
3. What minimum internal radius should we apply to pocket and gasket-land corners for your tooling?
4. Can you provide inspection reports for datum hole positions, pocket spacing, flatness, and gasket land width?
5. Do you recommend machining the lid and carrier as matched parts?
6. Can you source and install threaded inserts/captive hardware, or should hardware installation stay in-house?
7. What finish is compatible with repeated humid 37 C incubation and cleaning agents?
8. Can you quote one prototype set, three prototype sets, and a small pilot run?
9. Can you support CMM or optical inspection for the chip-pocket pattern and gasket land flatness?
10. Do you see any issue machining the gasket groove and chip pockets in the same setup to preserve relative alignment?

## Build/Test Sequence

1. Fit-check with dummy Rev C chips or gauge blocks.
2. Verify cassette lid closes without chip interference.
3. Measure gasket compression using witness shims/coupons before using live-cell hardware.
4. Leak-test the closed cassette with no cells and nonhazardous liquid.
5. Level the incubator/dock, inspect every through-deck clear span and
   void-below/solid-above bridge against D5, and document utility clearances
   before environmental tests.
6. Run 24-hour dry incubation with temp/RH/CO2 logging.
7. Run slot-to-slot evaporation balance with sterile water/media surrogate.
8. Run media exchange using dye to measure carryover, dead volume, bubbles, and per-slot uniformity.
9. Verify cleaning access and residue removal on gasket lands, pockets, dock
   clear spans, and additive bridge sections.
10. Only after those gates, consider live-cell compatibility testing in an appropriate lab environment.

## Research State

Existing repo research and the fresh Exa check support the direction: automated organ-chip systems exist, multi-chip fluidic circuit-board architectures are the right analogy, reusable clamped cassettes are credible, and a standardized cassette/dock is more realistic than single-chip handling. The saved baseline research notes are in `docs/automated_organ_chip_research.md` and `docs/cell_culture_starter_equipment.md`.

Fresh sources used:

- Modular reusable perfusion-ready MPS cassette: https://pmc.ncbi.nlm.nih.gov/articles/PMC12914553/
- Fluidic circuit board for parallelized cell culture: https://preview-www.nature.com/articles/s41378-020-00216-z
- Scalable standardized OOC platform with TEER: https://pmc.ncbi.nlm.nih.gov/articles/PMC11583584/
- Baker humidity/condensation white paper: https://bakerco.com/wp-content/uploads/dlm_uploads/2024/11/Controlling-Relative-Humidity-and-Condensation-in-a-ReCO2ver-Incubator-White-Paper.pdf
- PHCbi incubator selection guide: https://www.phchd.com/global/-/media/biomedical/global/WhitePaper/MCO/07_Choosing-Your-Cell-Culture-Incubator_web.pdf
- Thermo Fisher incubator care guide: https://www.thermofisher.com/TFS-Assets/LPD/Handbooks/incubator-care-and-maintenance.pdf
- Parker O-Ring Handbook: https://www.valin.com/sites/default/files/2023/asset/document/parker-o-ring-handbook.pdf

## Immediate Release Work Next

The dedicated `sixteen_slot_cassette_incubator_first_article.rs` STL fit-check generator and `sixteen_slot_cassette_first_article_step.rs` true B-rep STEP draft generator are implemented from the shared A0 contract. The immediate release work is to produce and review D0-D9 drawings, inspection tables, and the file/commit manifest, then select bought hardware and connector details. Do not send the STEP drafts for RFQ until those drawings exist.

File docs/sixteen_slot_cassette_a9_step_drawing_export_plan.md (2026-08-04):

# 16-Slot Cassette A9 STEP And Drawing Export Plan

Ticket: T-44807EA2

This A9 plan converts the A8 first-article build package into a concrete STEP and drawing release plan for vendor RFQ. It defines the export files, drawing sheets, critical dimensions, inspection tables, stackup drawing, and implementation rules needed to move from internal STL fit-checks to quote-ready manufacturing documents.

This is not a released drawing package, vendor quote packet, biological validation, sterile-barrier claim, AAV containment claim, or live-cell release criterion. It is the plan for producing those manufacturing files without silently treating STL output as production geometry.

## A9 Baseline

| Item | A9 requirement |
| --- | --- |
| First-build format | 16 slots in a 4 x 4 cassette. |
| Experimental unit | One cassette equals one AAV capsid/promoter/payload/dose/timing/media condition. |
| Active fit-check CAD | `src/bin/sixteen_slot_cassette_incubator_first_article.rs`. |
| Current export status | Seven STL fit-check files plus an implemented seven-file true B-rep STEP draft generated from the shared machine-readable A0 contract. The draft groove loops are square-cornered and omit the required entry break, so D2/D4 manufacturing geometry remains blocked. |
| RFQ export target | Implemented STEP drafts plus D0-D9 2D drawings, inspection tables, manifest, and release review. Drawings still block RFQ. |
| Manufacturing definition | Drawings control; STEP supports geometry; STL is not the manufacturing definition. |
| Wetted-path policy | Structural parts remain dry; bought disposable tubing/connectors remain the wetted path. |
| Biology status | No media-only, live-cell, or AAV release from drawing output alone. |

## Current Export Reality

The active STL fit-check and STEP draft generators export matching packages from `src/sixteen_slot_cassette_a0.rs`. Both complete additive lid/retention geometry before subtracting the same 1.80 x 3.20 mm underside groove loops; operation order is part of geometry parity, not merely an implementation detail:

| Fit-check STL | Implemented STEP draft | Drawing still required |
| --- | --- | --- |
| `output/sixteen_slot_cassette_lower_carrier.stl` | `output/rfq/sixteen_slot_cassette_lower_carrier.step` | D1 |
| `output/sixteen_slot_cassette_lid_clamp.stl` | `output/rfq/sixteen_slot_cassette_lid_clamp.step` | D2 |
| `output/sixteen_slot_cassette_window_placeholder.stl` | `output/rfq/sixteen_slot_cassette_window_placeholder.step` | D3 or controlled sheet drawing |
| `output/sixteen_slot_cassette_gasket_witness_coupon.stl` | `output/rfq/sixteen_slot_cassette_gasket_witness_coupon.step` | D4 |
| `output/sixteen_slot_incubator_dock_plate.stl` | `output/rfq/sixteen_slot_incubator_dock_plate.step` | D5 |
| `output/sixteen_slot_service_bulkhead_test_block.stl` | `output/rfq/sixteen_slot_service_bulkhead_test_block.step` | D6 |
| `output/sixteen_slot_cassette_incubator_first_article_assembly.stl` | `output/rfq/sixteen_slot_cassette_stackup_reference.step` | D7 assembly/section reference |

Do not send the current STL files alone to a manufacturer except as supplemental visual references. A4 and A8 both require STEP files and drawings for RFQ.

## STEP Export Strategy

The implemented `src/bin/sixteen_slot_cassette_first_article_step.rs` uses the repo's OpenCascade `step` feature and `Shape::write_step(...)` precedent. It emits true B-rep draft geometry rather than converting STL triangles.

Implemented direction and remaining release rules:

- Keep the implemented OpenCascade-backed cassette STEP export bin as the common-contract draft source rather than relying on `vcad` STL triangles as the release source.
- Keep the current `sixteen_slot_cassette_incubator_first_article` STL bin as fit-check and visual review output.
- Preserve parity-equivalent lid construction order in both generators: finish
  additive frame, crossbar, and retention features first, then subtract the
  shared-contract gasket grooves. A groove cut made before a later union is not
  equivalent and must fail parity review.
- Keep deterministic STEP names under `output/rfq/`; decide separately whether a reviewed release bundle should be committed. Re-import every file in a separate OpenCascade verifier pass and require one closed solid for each standalone part.
- Fail immediately if the selected STEP export dependency, feature flag, or converter is unavailable during an RFQ export run.
- Do not use the existing `stl_to_step` helper as the RFQ release path because it converts triangulated STL faces and currently skips/fails softly when `stltostp` is missing.
- If STL-to-STEP conversion is used at all, label it `non-release mesh-derived STEP` and require vendor approval before quoting.

Authoritative execution uses the LaminarForge MCP runner with `action: run`,
`bin: sixteen_slot_cassette_first_article_step`, and `features: ["step"]`.
The runner sets the required CMake compatibility environment. The underlying
Cargo command belongs in the evidence artifact, not the operator procedure.

The exporter creates six custom-part STEP files and one stackup/reference STEP
file, then asserts all files exist. Missing files, failed export, failed
separate re-import, or a standalone part with more than one closed solid fail
the release evidence gate. STEP headers contain timestamps, so file SHA-256
values identify a particular run and are not stable geometry baselines.

## Drawing Set

A9 requires the following drawing sheets before RFQ.

| Sheet | File | Purpose |
| --- | --- | --- |
| D0 | `sixteen_slot_cassette_drawing_index.pdf` | Drawing index, revision table, no-biological-claim note, file manifest, and controlling specs. |
| D1 | `sixteen_slot_cassette_lower_carrier.pdf` | Carrier manufacturing definition. |
| D2 | `sixteen_slot_cassette_lid_clamp.pdf` | Lid/clamp manufacturing definition. |
| D3 | `sixteen_slot_cassette_window_placeholder.pdf` | Window sheet/placeholder definition. |
| D4 | `sixteen_slot_cassette_gasket_witness_coupon.pdf` | Coupon manufacturing and inspection definition. |
| D5 | `sixteen_slot_incubator_dock_plate.pdf` | Dock plate manufacturing definition. |
| D6 | `sixteen_slot_service_bulkhead_test_block.pdf` | Service bulkhead placeholder definition. |
| D7 | `sixteen_slot_cassette_stackup_and_sections.pdf` | Cross-section stackup, gasket compression, chip seating, and window/lid/carrier relationship. |
| D8 | `sixteen_slot_cassette_inspection_plan.pdf` | Consolidated critical inspection table and pass/fail evidence log. |
| D9 | `sixteen_slot_cassette_rfq_notes.pdf` | Vendor questions, quote options, assumptions, and explicit blockers. |

Drawings should be PDF for RFQ plus editable source if the selected CAD/drawing tool supports it. Do not bury critical tolerances in markdown only.

## Part Drawing Requirements

### D1 Lower Carrier

Drawing must include:

- Base-body dimensions: 699.04 x 541.92 x 24.00 mm; true overall bounds: 699.04 x 541.92 x 31.35 mm.
- A0 slot map and S01-S16 row-major orientation.
- 24.00 x 24.00 mm inter-chip gutter, 151.76 x 109.48 mm pitch, 583.04 x 413.92 mm array, and X/Y center coordinates +/-227.64, +/-75.88 / +/-164.22, +/-54.74 mm.
- Rev C chip pocket size, pocket depth, and optical through-window size.
- Explicit note that 1.20 mm per-side pocket clearance is the current CAD fit-check baseline.
- Manufacturer-drawing pocket target from A1: measured maximum Rev C chip lot plus 0.80 mm per side, with 0.50 mm per side minimum accepted clearance.
- Bottom plane datum A seated directly on the dock support plane; nominal rear
  edge datum B and left edge datum C contact the corresponding dock rail inner
  faces, and the nominal front edge contacts the front lip.
- D1-D4 coordinates at X = +/-335.52 mm and Y = +/-204.96 mm. D1 is the 6.00 mm round functional locator; D2 is a 10.00 x 6.00 X-oriented relieved slot; D3/D4 are 9.00 mm clearance/witness bores.
- Sixteen independent per-slot gasket lands: 145.76 x 103.48 mm outer, 129.76 x 87.48 mm inner, 8.00 mm width, 7.35 mm height, and 6.00 mm gap between adjacent outer edges.
- Perimeter gasket land: 629.04 x 459.92 mm outer, 605.04 x 435.92 mm inner, 12.00 mm width, and 7.35 mm height.
- Nine 4.00 mm-diameter internal hard stops at the 3 x 3 inter-slot gap
  intersections and distributed 4.00 mm-wide perimeter stops centered in the
  5.00 mm seal-to-gutter web. All top out at 7.35 mm and no stop intersects a
  seal; per-slot corner stops are prohibited.
- Sixteen 3.30 mm carrier-side M4 tap-drill/pilot receiver placeholders matching
  the D2 fastener centers. Final thread/insert SKU remains open.
- Side service reliefs are 7.00 mm high above carrier top and below closure.
- Leak gutter: 651.04 x 481.92 mm outer, 639.04 x 469.92 mm inner, 6.00 mm width, 3.00 mm depth, and 5.00 mm intact web to the perimeter land.
- Drain: 8.00 mm diameter, center (315.52, -254.96, 10.00) mm, 40.00 mm length along Y.
- Global 96.00 x 12.00 mm barcode land at (-271.52, -263.96) mm and adjacent
  118.00 x 10.00 mm text land at (-159.52, -263.96) mm, both outside the leak
  gutter and clear of the front receiver row; per-slot labels, compression-stop
  references, and handling lands.
- Material/finish: 6061-T651/T6 dry structural aluminum baseline, clear Type II anodize option with critical surfaces controlled after finish.

Minimum inspection table:

| Feature | Starting target |
| --- | --- |
| Pocket array true position | 0.25 mm relative to A/B/C. |
| Local adjacent slot pitch | +/-0.10 mm. |
| Pocket X/Y size | +0.20 / -0.00 mm from selected clearance target. |
| Pocket depth | +/-0.10 mm. |
| D1 locator bore | 6 mm H7 or vendor-equivalent after pin selection. |
| D1 true position | 0.10 mm relative to A/B/C. |
| D2 slot/locator true position | 0.15 mm relative to A/B/C and D1. |
| D3/D4 witness hole position | 0.30 mm; non-locating clearance/witness features only. |
| Per-slot gasket land flatness | 0.05 mm over each seal loop. |
| Gasket land / hard-stop height | 7.35 mm nominal, +/-0.03 mm starting target after finish. |
| Carrier receiver pilot diameter | 3.30 mm at all 16 locked centers before final thread/insert process. |
| Carrier bottom support face flatness | 0.25 mm over full carrier. |
| Seal band finish | Ra 0.8 um target and Ra 1.6 um hard maximum; a gasket vendor may require smoother. |

### D2 Lid/Clamp

Drawing must include:

- Base-body dimensions: 717.04 x 559.92 x 10.00 mm; true overall bounds: 717.04 x 559.92 x 11.60 mm.
- One-part lid construction: 4.00 mm continuous underside sealing skin plus
  6.00 mm upper frame. The 635.04 x 457.92 mm center lightening relief cuts only
  the upper frame.
- Sixteen lid view openings: 113.76 x 71.48 mm.
- Sixteen underside chip-top reliefs: 130.16 x 87.88 mm x 0.50 mm deep, leaving
  2.20 mm to the inner gasket-groove edge in X/Y.
- Carrier optical opening reference: 103.76 x 61.48 mm.
- 16-fastener M4 baseline outside the gutter: side X = +/-332.52 mm at the four slot-center Y values and front/rear Y = +/-247.96 mm at the four slot-center X values.
- Captive screw counterbore/retainer placeholders or hold note if final hardware is not selected.
- Matching 3.30 mm carrier pilot receiver reference at every fastener center.
- Lid-to-carrier datum/alignment ears and orientation prevention detail.
- D1/D2 replaceable-pin seats: 6.00 mm diameter x 4.00 mm deep. Show the 5.80 mm
  diameter x 7.35 mm fit-check surrogate only in D7 assembly/section views;
  standalone lid manufacturing geometry contains no pins, and D3/D4 contain no
  pin seats.
- Crossbar network and imaging keepouts.
- Window retention ledge/shoulder or explicit placeholder hold.
- Torque sequence mark locations.
- Sixteen per-slot and one perimeter 1.80 mm-deep x 3.20 mm-wide underside
  groove loops, cut after additive lid/retention geometry so STEP and STL are
  parity-equivalent.
- Groove floor: 2.20 mm nominal / 2.00 mm minimum. Adjacent loop gap: 10.80 mm;
  per-slot array to perimeter groove: 8.80 mm; perimeter groove to lid edge:
  48.40 mm X / 54.40 mm Y.
- Material/finish and gasket-facing flatness callouts.

Minimum inspection table:

| Feature | Starting target |
| --- | --- |
| Lid view opening X/Y size | +/-0.20 mm. |
| Fastener hole position | +/-0.15 mm unless hardware requires tighter; verify every retainer clears the gutter. |
| Gasket groove | 1.80 mm depth x 3.20 mm width nominal; depth +/-0.03 mm after finish. |
| Alignment feature true position | 0.10-0.15 mm relative to lid datums after carrier strategy is frozen. |
| Gasket-facing flatness | 0.15 mm total over clamp face; tighter local targets if vendor review supports it. |
| Lid elastic deflection allowance | 0.10 mm planning allocation until FEA or metrology replaces it. |
| Captive hardware fit | Vendor/hardware drawing controlled. |

### D3 Window Placeholder

Drawing must include:

- Base panel: 667.04 x 489.92 x 3.00 mm; true overall bounds: 667.04 x 489.92 x 4.80 mm.
- Per-slot witness frames and three calibration rings. Every raised feature must
  be fused to the panel; calibration rings expose 1.80 mm above the panel with a
  0.20 mm modeling overlap. Floating solids fail D3 export review.
- Retention tab/ledge relationship to lid.
- Material options: polycarbonate fit-check baseline, borosilicate/glass alternate.
- Edge deburr/chamfer note and no point-loading note.
- Imaging surfaces and cleaning compatibility hold.

If a sheet drawing is simpler than STEP, D3 may use a flat pattern drawing plus thickness and material notes.

### D4 Gasket Witness Coupon

Drawing must include:

- Coupon envelope: 250.00 x 118.00 x 12.00 mm from active CAD.
- Same 1.80 mm groove depth, 3.20 mm groove width, seal-band finish, 7.35 mm closure-contact stop logic, and hardware style as final cassette gasket interfaces.
- A3 baseline: 2.40 mm gasket free height, 1.80 mm target compressed height, 1.68-1.92 mm accepted guard band.
- Locked nominal groove: 1.80 mm depth, 3.20 mm width, 0.20 mm minimum entry break, vendor-reviewed corner radius and tolerance.
- Coupon labeling for 20%, 25%, and 30% squeeze references.
- Leak, burst, reconnection, and soak coupon traceability fields.

Minimum inspection table:

| Feature | Starting target |
| --- | --- |
| Groove depth | +/-0.03 mm after finish/coating strategy. |
| Groove width | +/-0.05 mm unless vendor/gasket supplier changes target. |
| Compression stop height | +/-0.03 mm. |
| Seal land finish | Ra 0.8 um target and Ra 1.6 um hard maximum; a gasket vendor may require smoother. |
| Coupon flatness | Match cassette seal-band drawing notes. |

### D5 Incubator Dock Plate

Drawing must include:

- Base-body dimensions: 869.04 x 691.92 x 22.00 mm; true overall bounds: 869.04 x 691.92 x 40.00 mm.
- Rear rail, left rail, front low retention lip, dock leveling pads, logger pockets, robot lift lands, drain gutters, and visible sump.
- Direct datum-A support plane and rail/lip inner faces positioned to contact the
  nominal rear, left, and front carrier edges without spacer or recess offset.
- Note that CO2 incubation and environmental control are reserved, not solved by this dock.

Minimum inspection table:

| Feature | Starting target |
| --- | --- |
| Dock cassette support flatness | 0.25 mm over cassette support region. |
| Rear/left rail squareness and edge contact | Vendor-reviewed; inner faces contact nominal carrier edges and must not twist carrier. |
| Rail/contact edge burr state | No burrs or coating buildup that shifts cassette datum. |
| Drain/sump visibility | Visual inspection with cassette docked. |
| Logger pocket size | +/-0.20 mm unless logger SKU is selected. |

### D6 Service Bulkhead Test Block

Drawing must include:

- Base-body dimensions: 789.04 x 34.00 x 76.00 mm; true overall bounds: 789.04 x 60.00 x 76.00 mm.
- Current placeholder gas/media/waste holes and sensor/backplane cut.
- A6 logical port labels G0-G3, M0-M6, W0-W4.
- Sensor/backplane cut center X = 320.00 mm and center Z = 18.00 mm; preserve clearance from W4.
- Explicit note that placeholder diameters are not final connector cutouts.
- Cap/plug status and label-strip requirements.
- Dry structural role; no custom machined sterile port claim.

RFQ drawings should either leave connector cutouts as placeholders for no-cell fit-check or wait until selected bought connector datasheets define panel geometry.

### D7 Stackup And Sections

Stackup drawing must include:

- Carrier, Rev C chip surrogate, gasket, lid/clamp, window placeholder, hard stops, and dock support in section.
- Per-slot and perimeter gasket land height: 7.35 mm above carrier top on one common plane meeting the lid underside.
- Gasket free height: 2.40 mm.
- Target compressed height: 1.80 mm.
- Lid groove cavity: 1.80 mm deep x 3.20 mm wide; compressed gasket resides in
  this cavity rather than in a gap above a shorter land.
- Guard band: 1.68-1.92 mm.
- Pocket depth: 7.00 mm.
- Chip total height: 14.35 mm.
- Nominal chip protrusion and closure plane: 7.35 mm above carrier top.
- Lid local chip-top clearance: 0.50 mm; show that the sealing face still meets
  lands/stops and that the relief remains 2.20 mm from the groove.
- Replaceable D1/D2 pin stack: 4.00 mm lid embedment, 3.35 mm projection, and
  2.00 mm carrier-boss engagement; D3/D4 remain pin-free.
- Nine 4.00 mm-diameter inter-slot hard stops and 4.00 mm-wide perimeter web
  stops at the same 7.35 mm plane, with no seal intersection.
- Direct carrier-bottom contact on dock datum A and nominal rear/left/front edge
  contact at the dock rails/lip.
- Optical line-of-sight through carrier and lid openings.
- Drain/leak witness path and tubing keepout zones.

D7 must include a signed worst-case calculation, not a nominal-only review. At
every required seal witness location, define delta_local as the local
land-to-stop plane error after part flatness, coating, datum seating, stop/land
height variation, lid deflection, and measurement uncertainty. Prove:

1.68 mm <= groove_depth + delta_local <= 1.92 mm

using worst-case limits for release and showing RSS only as supplemental
process-capability information. List every contributor, sign, tolerance,
inspection method, and governing drawing dimension. A missing contributor or
failed inequality blocks D7 and RFQ release.

D7 remains the highest-risk drawing because it exposes whether the physical tolerance stack preserves the common 7.35 mm closure plane. The prior overlapping loops and 3.00/4.00 mm unequal land elevations were corrected in the shared A0 contract; drawings must not revive them.

### D8 Inspection Plan

D8 should consolidate all critical measurements into one vendor-facing table:

- Part number and revision.
- Feature ID.
- Drawing zone.
- Nominal value.
- Tolerance or GD&T frame.
- Datum reference.
- Inspection method.
- Sample quantity.
- Acceptance rule.
- Vendor report required: yes/no.

Feature IDs should be stable, for example:

- CAR-PKT-001 through CAR-PKT-016 for chip pockets.
- CAR-DAT-D1 through CAR-DAT-D4 for datum bosses/bores.
- CAR-SEAL-S01 through CAR-SEAL-S16 for slot seal lands.
- LID-WIN-S01 through LID-WIN-S16 for lid view openings.
- LID-FST-001 through LID-FST-016 for fastener holes.
- CAR-RCV-001 through CAR-RCV-016 for the 3.30 mm carrier pilot receivers.
- CAR-STP-I01 through CAR-STP-I09 and CAR-STP-P01 onward for internal and
  perimeter hard stops.
- GSK-GRV-001 for coupon groove.
- DCK-RAIL-B and DCK-RAIL-C for dock rails.
- BLK-M0 through BLK-W4 for service bulkhead logical ports.

### D9 RFQ Notes

D9 should carry the A4/A8 vendor notes:

- Quote one prototype set, three prototype sets, and pilot quantity separately.
- Separate DFM comments from price.
- Quote 6061-T651 clear anodized baseline, no-anodize/chem-film option, 316 stainless option, matched carrier/lid machining option, CMM inspection add-on, and flatness-relaxed option.
- Ask whether carrier and lid should be machined or inspected as a matched pair.
- Ask whether seal bands and datum bores should be masked, post-machined, or inspected after anodize.
- Ask for vendor minimum radii for pockets, gasket grooves, drain gutters, and bulkhead cutouts.
- Ask for cleaning compatibility notes for humid 37 C exposure and likely wipe agents.
- State that the first quote is mechanical/no-cell only.

## Drawing Notes To Carry Forward

Use these notes unless a selected vendor or subsystem revision replaces them:

- Material: 6061-T651 aluminum plate unless otherwise specified.
- Finish: clear Type II anodize, natural, with critical seal bands and precision bores controlled after finish or masked per drawing.
- General tolerance: ISO 2768-m unless otherwise specified.
- Break all noncritical sharp edges 0.25-0.50 mm.
- Do not break, polish, or blend gasket compression stops beyond specified tolerance.
- Seal bands: Ra 0.8 um target and Ra 1.6 um hard maximum; a gasket vendor may require smoother, never rougher.
- General machined faces: Ra 3.2 um max unless otherwise specified.
- No burrs, loose media, sharp chips, or embedded blasting residue.
- Dimensions for gasket groove depth, compression stop height, precision bores, and pocket size apply after coating unless explicitly marked pre-coat.
- Vendor to provide inspection report for critical dimensions listed on drawing.
- Part is dry reusable structural hardware for no-cell first-article testing; sterile/wetted path is not claimed by this drawing.

## Release Acceptance Criteria

The STEP implementation portion of A9 exists as a draft. A9 is not RFQ-complete until all of these pass:

- STEP export command creates all six part STEP files and one stackup/reference STEP file.
- Export command fails immediately if STEP dependencies, feature flags, or output writes fail.
- `sixteen_slot_cassette_step_verify` re-imports every STEP successfully and records closed-solid count, nonempty topology, A0 bounds, and file hash for the release commit.
- Drawing index lists every STEP, drawing, revision, and controlling spec.
- D0-D9 drawings exist as PDFs or selected drawing-source outputs.
- Drawings include no-biological-claim notes.
- Inspection table includes carrier pockets, datums, gasket lands, lid openings, fastener pattern, dock rails, bulkhead ports, surface finish, flatness, coating, and deburr checks.
- D7 stackup is reviewed against the common 7.35 mm land/stop elevation, lid
  underside contact, and 1.80 mm groove cavity.
- A8 build package is updated from "blocked by drawings" to "RFQ package generated" only after drawings exist.
- Ticket artifact records command output, file manifest, and unresolved deviations.

## Implementation Tasks

Recommended next implementation tasks:

1. Done: add `src/bin/sixteen_slot_cassette_first_article_step.rs` using the `step` feature and OpenCascade B-rep primitives.
2. Done: export the six custom part STEP files and stackup/reference STEP file with hard-fail assertions.
3. Decide whether generated `output/rfq/` output remains ignored or whether a reviewed zipped RFQ release artifact should be committed under a controlled release directory.
4. Create drawing-source templates or markdown-to-PDF drawing notes for D0-D9.
5. Add a manifest generator that records file names, commit hash, export command, dimensions, and no-biological-claim notes.
6. Update A8 from "blocked by drawings" only after the actual D0-D9 drawing package exists.

## Explicit Blockers

- Do not send STL files alone as a vendor manufacturing definition.
- Do not use mesh-derived STEP as release geometry unless explicitly labeled and accepted by the vendor.
- Do not silently skip STEP output when a dependency is missing.
- Do not release a drawing set without D7 stackup review of gasket compression.
- Do not reintroduce the obsolete overlapping per-slot lands, unequal 3.00/4.00
  mm or interim shorter land elevations, per-slot corner stops, fasteners inside
  the gutter, or pre-contract base dimensions into drawings.
- Do not claim sterility, live-cell readiness, AAV containment, or biological compatibility from STEP/drawing output.
- Do not change slot count, slot centers, one-condition semantics, or disposable wetted-path policy without revising A0.

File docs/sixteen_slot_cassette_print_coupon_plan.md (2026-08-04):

# 16-Slot Cassette Printable Coupon Plan

Ticket: T-5C29EBD8

Architecture status: active mechanical-learning precursors for the 16-slot,
4 x 4 first physical cassette. These local coupons retire fit, gasket, datum,
and connector risks before a full-size carrier is fabricated. They do not by
themselves satisfy the integrated first-article or vendor-release gates.

This document defines the first dry, desktop-printable validation coupons for the LaminarForge 16-slot cassette. These prints are for mechanical learning only. They are not sterile parts, live-cell parts, AAV-contact parts, or vendor-release geometry.

The coupons do not change experimental semantics: one cassette remains one AAV
capsid/promoter/payload/dose/timing/media condition, and the 16 slots are
same-condition readouts rather than separate candidate lanes.

## Why Coupons First

The active carrier alone is 699.04 x 541.92 mm and the dock base is 869.04 x
691.92 mm before the service bulkhead and separate coupon are included, so the
integrated hardware is too large for normal desktop printers. Printing the
whole thing would also hide the most important early questions. The first useful checks are local:

- Does a Rev C chip physically seat in the pocket with the current 1.20 mm/side CAD clearance?
- Can the gasket groove and hard-stop concept be printed and inspected?
- Does the rear/left dock datum scheme make physical sense?
- Are the bulkhead port spacing, label strip, and tubing strain-relief comb ergonomic?

## Generator

`sixteen_slot_cassette_print_coupons` consumes the shared machine-readable A0
contract for chip, seal, groove, stop, datum, and dock-interface values. Coupon
envelopes and fixture-only offsets may remain local, but the generator must not
duplicate or override cassette constants.

Run:

```text
mcp__agentic_mcp.laminarforge_build action=run repo=laminarforge-cad bin=sixteen_slot_cassette_print_coupons
```

Output directory:

```text
output/print_coupons/
```

## Coupon Outputs

| Output | Approx envelope | Checks |
| --- | ---: | --- |
| `sixteen_slot_chip_pocket_fit_coupon.stl` | 168 x 126 x approximately 31.35 mm | Rev C chip seating, 1.20 mm/side CAD pocket clearance, pocket depth, optical through-window, 7.35 mm gasket land, and representative portions of the shared 4.00 mm inter-slot hard-stop pattern without a seal intersection. These are coupon representations of array intersections, not a per-slot corner-stop definition. Slot-label land is intentionally omitted because it is not needed for pocket-fit evidence. |
| `sixteen_slot_gasket_compression_coupon.stl` | 190 x 88 x 14 mm | 3.20 mm groove width, 1.80 mm groove depth, 20/25/30% compression guard heights, and printability of small gasket features. |
| `sixteen_slot_dock_datum_rail_coupon.stl` | 198 x 178 x 40 mm | Direct datum-A carrier support, rear primary and left secondary rail inner-face contact, front low-lip contact at the nominal carrier edge, visible leak gutter, and mounting holes. |
| `sixteen_slot_carrier_corner_surrogate.stl` | 156 x 132 x 39 mm | Mating corner piece for the dock datum rail coupon; checks registration and handling/orientation features. |
| `sixteen_slot_bulkhead_connector_mockup.stl` | 232 x 76 x 76 mm | M0-M6 media port spacing, partial waste-port spacing, label strip, mounting access, and tubing comb ergonomics. |

## Printer Guidance

Use the Bambu for the larger dry-fit coupons first. PLA or PETG is enough for geometry checks. Use resin only for small-feature checks where surface detail matters, especially gasket groove inspection.

Local Bambu Studio inspection on the Mac found one configured Bambu device access-code entry but no saved user machine preset naming the exact connected model. The installed Bambu machine profiles show the common Bambu 0.4 mm nozzle family, with the shared `fdm_bbl_3dp_001_common` profile defining a 256 mm x 256 mm printable area and the A1 0.4 nozzle profile defining `printable_height = 256`. Treat 256 mm x 256 mm x 256 mm as the conservative Bambu target until Alex confirms a larger H2D/H2S-class machine.

All current coupons fit that conservative Bambu target. They do not fit an A1 mini target without scaling or splitting; do not scale the chip pocket coupon because it must remain 1:1 for fit evidence.

Suggested first print order:

1. `sixteen_slot_chip_pocket_fit_coupon.stl`
2. `sixteen_slot_gasket_compression_coupon.stl`
3. `sixteen_slot_dock_datum_rail_coupon.stl` plus `sixteen_slot_carrier_corner_surrogate.stl`
4. `sixteen_slot_bulkhead_connector_mockup.stl`

## What To Measure

Record these before changing the cassette baseline:

| Check | Measurement |
| --- | --- |
| Pocket fit | Actual chip length/width, printed pocket length/width, subjective insertion force, rocking, visible binding, burr/contact points. |
| Raised pocket features | Confirm the 7.35 mm gasket land and representative 4.00 mm shared inter-slot stops are fused to the base, remain separate from the seal path, and are not interpreted as per-slot corner stops. |
| Pocket depth | Printed pocket depth at four corners and center. |
| Optical window | Whether the center opening leaves enough support and does not warp. |
| Gasket groove | Printed groove width/depth, corner cleanup, whether gasket seats without twisting. |
| Compression stops | Stop height at each squeeze lane and whether a straightedge rocks. |
| Dock datums | Whether the carrier surrogate seats directly on datum A and repeats against the rear/left rail inner faces and front lip at its nominal edges without wedging. |
| Bulkhead | Finger access, connector spacing, label visibility, tube bend/comb behavior. |

## Hard Boundaries

- Do not put cells, media, AAV, or sterile tubing through printed structural coupons.
- Do not treat a printed coupon pass as vendor drawing release.
- Do not reduce the official chip pocket clearance from 1.20 mm/side to 0.80 mm/side until real chip lot measurements and printed/ machined evidence exist.
- Do not freeze connector SKUs from the bulkhead mockup; it only checks spacing and ergonomics.

## Next After Printing

After the first prints, capture measured deviations and decide which CAD assumptions need revision:

- Pocket clearance and corner/radius policy.
- The locked 1.80 x 3.20 mm gasket groove, 7.35 mm land/stop height, and absence
  of seal/stop intersections.
- Datum-A seating plus rear/left rail and front-lip nominal-contact fit and tolerance behavior.
- Bulkhead connector spacing, label strip, and strain-relief comb geometry.

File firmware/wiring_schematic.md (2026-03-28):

# LaminarForge Liquid Handler -- Wiring Schematic

**Ticket:** T-F5D355C5
**Date:** 2026-03-28
**References:** OTTO liquid handler (optocoupler limit switches), MULA 4-axis architecture

---

## System Overview

The LaminarForge liquid handler uses a dual-controller architecture:

| Controller | MCU | Role | Power Rail |
|---|---|---|---|
| Motion Controller | ESP32-S3 #1 | FluidNC firmware, 4-axis stepper control | 24V / 5V / 3.3V |
| Environmental Controller | ESP32-S3 #2 | PID temp, CO2, humidity, rocker servo | 12V / 5V / 3.3V |

Communication between controllers is via a single GPIO signal line (motion-interlock) with optional UART for richer messaging.

---

## 1. Power Distribution

```
                    +-----------+
   AC Mains ------->| 24V PSU   |----+---> 24V Rail (steppers, heater pads)
                    | (350W)    |    |
                    +-----------+    |
                                     |
                              +------+------+
                              |             |
                        +-----v-----+ +-----v-----+
                        | LM2596    | | LM2596    |
                        | 24V->12V  | | 24V->5V   |
                        | Buck      | | Buck      |
                        +-----+-----+ +-----+-----+
                              |             |
                              v             v
                         12V Rail       5V Rail
                    (solenoid, fan,   (servo, ESP32
                     Peltier, CO2)    via USB or
                                       LDO -> 3.3V)
                                            |
                                      +-----v-----+
                                      | AMS1117   |
                                      | 5V->3.3V  |
                                      | LDO       |
                                      +-----+-----+
                                            |
                                            v
                                        3.3V Rail
                                   (sensors, TMC UART,
                                    ESP32 GPIO logic)
```

### Power Budget Estimates

| Load | Voltage | Max Current | Notes |
|---|---|---|---|
| 4x NEMA 17 steppers | 24V | 4.0A total | 1.0A RMS each via TMC2209 |
| 2x Silicone heater pads | 24V | 4.0A total | ~50W each |
| 2x TEC1-12706 Peltier | 12V | 12.0A total | 6A each at full drive |
| 1x 12V solenoid | 12V | 0.5A | CO2 valve |
| 1x 12V fan | 12V | 0.3A | Circulation fan |
| 1x SprintIR-6S-5 | 3.3V | 0.035A | CO2 sensor |
| 1x BME280 | 3.3V | 0.001A | Humidity/temp/pressure |
| 2x DS18B20 | 3.3V | 0.002A | Temperature probes |
| 1x MG996R servo | 5V | 2.5A peak | Rocker platform |
| 2x ESP32-S3 | 5V (USB) | 0.5A each | Via USB or 5V rail |

**Total estimated 24V draw:** ~8A continuous (16A peak with heaters + steppers)
**Recommended PSU:** 24V / 15A (360W) with headroom

### Fusing

| Circuit | Fuse Rating | Type |
|---|---|---|
| 24V main rail | 15A | Blade fuse, inline |
| 24V stepper branch | 6A | Blade fuse |
| 24V heater branch | 8A | Blade fuse |
| 12V rail (after buck) | 15A | Blade fuse (Peltier draw) |
| 5V rail (after buck) | 5A | Blade fuse |

---

## 2. Motion Controller (ESP32-S3 #1 -- FluidNC)

### 2.1 TMC2209 Stepper Drivers (UART Mode)

All four TMC2209 drivers share a single UART bus. Each driver is addressed via the MS1/MS2 pin configuration. The ESP32 communicates with each driver individually using its 2-bit address.

#### TMC2209 UART Address Configuration

| Driver | Axis | MS1 | MS2 | UART Address |
|---|---|---|---|---|
| TMC2209 #1 | X (gantry left-right) | GND | GND | 0b00 (0) |
| TMC2209 #2 | Y (gantry forward-back) | VCC_IO | GND | 0b01 (1) |
| TMC2209 #3 | Z (pipette up-down) | GND | VCC_IO | 0b10 (2) |
| TMC2209 #4 | I (syringe pump) | VCC_IO | VCC_IO | 0b11 (3) |

**MS1/MS2 Notes:**
- Directly tie MS1/MS2 to GND or VCC_IO (3.3V) -- do NOT leave floating.
- VCC_IO on TMC2209 is typically 3.3V (from the on-board regulator or external 3.3V).
- If using Bigtreetech TMC2209 modules, MS1/MS2 pads are on the bottom of the PCB.

#### UART Wiring

The TMC2209 UART is a single-wire bidirectional protocol, but for reliability we use two ESP32 GPIOs with a 1kOhm resistor on the TX line:

```
ESP32 GPIO17 (TMC_UART_TX) ---[1kOhm]---+--- TMC2209 #1 PDN_UART
                                         +--- TMC2209 #2 PDN_UART
ESP32 GPIO18 (TMC_UART_RX) -------------+--- TMC2209 #3 PDN_UART
                                         +--- TMC2209 #4 PDN_UART
```

**Alternative (single-wire):** Tie TX and RX together through a 1kOhm resistor on TX, connect all PDN_UART pins to the junction. FluidNC supports this via `uart_num: 1` in the YAML config.

#### Pin Assignment -- Motion Controller

| ESP32-S3 GPIO | Function | Connected To | Notes |
|---|---|---|---|
| GPIO1 | X_STEP | TMC2209 #1 STEP | |
| GPIO2 | X_DIR | TMC2209 #1 DIR | |
| GPIO3 | Y_STEP | TMC2209 #2 STEP | |
| GPIO4 | Y_DIR | TMC2209 #2 DIR | |
| GPIO5 | Z_STEP | TMC2209 #3 STEP | |
| GPIO6 | Z_DIR | TMC2209 #3 DIR | |
| GPIO7 | I_STEP | TMC2209 #4 STEP | Syringe pump axis |
| GPIO8 | I_DIR | TMC2209 #4 DIR | |
| GPIO9 | STEPPER_EN | All TMC2209 EN (shared) | Active LOW, shared enable |
| GPIO17 | TMC_UART_TX | All TMC2209 PDN_UART | Via 1kOhm series resistor |
| GPIO18 | TMC_UART_RX | All TMC2209 PDN_UART | Direct connection |
| GPIO10 | X_MIN_LIMIT | Optocoupler output | Active LOW with pullup |
| GPIO11 | Y_MIN_LIMIT | Optocoupler output | Active LOW with pullup |
| GPIO12 | Z_MIN_LIMIT | Optocoupler output | Active LOW with pullup |
| GPIO13 | I_MIN_LIMIT | Optocoupler output | Active LOW with pullup |
| GPIO14 | MOTION_INTERLOCK | To Env Controller GPIO14 | OUTPUT: HIGH=moving |
| GPIO15 | PROBE_PIN | Optional Z-probe | For deck calibration |
| GPIO16 | COOLANT_FLOOD | Optional aux relay | Future expansion |
| GPIO43 | USB_TX (UART0) | USB-C debug console | FluidNC serial output |
| GPIO44 | USB_RX (UART0) | USB-C debug console | FluidNC serial input |

#### TMC2209 Wiring Per Driver

Each TMC2209 module connections:

```
                    +------------------+
      24V --------->| VM               |
      GND --------->| GND              |
                    |                  |
  ESP32 STEP ------>| STEP             |-----------> Stepper Coil A+
  ESP32 DIR ------->| DIR              |-----------> Stepper Coil A-
  ESP32 EN -------->| EN    TMC2209    |-----------> Stepper Coil B+
                    |                  |-----------> Stepper Coil B-
  MS1 (per table)-->| MS1              |
  MS2 (per table)-->| MS2              |
                    |                  |
  UART bus -------->| PDN_UART         |
                    |                  |
      3.3V -------->| VCC_IO           |
                    +------------------+
```

#### TMC2209 Current Settings

For NEMA 17 motors rated at 1.5A peak (1.06A RMS):

- **Target RMS current:** 1.0A (leaving ~6% margin)
- **UART configuration (preferred):** Set via FluidNC YAML or StallGuard registers
  - `run_current: 1000` (mA RMS) in FluidNC config
  - `hold_current: 500` (mA RMS) -- 50% for idle hold
- **VREF (if not using UART current control):**
  - V_ref = I_RMS x 1.41 x R_sense x 2
  - V_ref = 1.0 x 1.41 x 0.11 x 2 = 0.31V (measure at VREF test point)
- **Rsense on typical TMC2209 boards:** 0.11 Ohm

**StealthChop / SpreadCycle:**
- Enable StealthChop for quiet operation below ~100mm/s
- SpreadCycle auto-engages above velocity threshold
- Configure via UART: `tpwmthrs: 100` in FluidNC

### 2.2 Limit Switches (Optocoupler-Isolated)

Per the OTTO liquid handler design, limit switches use optocoupler isolation for noise immunity in the 24V stepper environment.

#### Optocoupler Circuit (per switch)

```
   3.3V (ESP32 side)
     |
    [4.7kOhm] pullup
     |
     +-----------> ESP32 GPIO (X/Y/Z/I_MIN)
     |
   +-+--+
   |    | PC817
   | OC |  Optocoupler
   |    |
   +-+--+
     |
    GND (ESP32 side)

--- isolation barrier ---

   24V (motor side)         Limit Switch
     |                      (NC, normally closed)
    [1kOhm]                     |
     |                          |
     +------[LED anode]---------+
                |
            [LED cathode]
                |
               GND (motor side)
```

**Component:** PC817 or similar (CTR > 50%)

**Switch wiring:**
- Use NC (normally closed) limit switches for fail-safe operation
- When switch is triggered (opens), optocoupler LED turns off, output goes HIGH
- ESP32 reads HIGH = switch triggered, LOW = not triggered
- Configure in FluidNC as active HIGH or invert in software

**Wire routing:**
- Use shielded cable for limit switch wires running near stepper motors
- Keep limit switch wires physically separated from stepper motor cables
- Tie shield to motor-side GND at one end only

---

## 3. Environmental Controller (ESP32-S3 #2)

### 3.1 Pin Assignment -- Environmental Controller

| ESP32-S3 GPIO | Function | Connected To | Notes |
|---|---|---|---|
| GPIO1 | DS18B20_DATA | 2x DS18B20 (1-Wire bus) | 4.7kOhm pullup to 3.3V |
| GPIO2 | HEATER_PAD_1 | IRLZ44N gate (heater 1) | Via 100Ohm gate resistor |
| GPIO3 | HEATER_PAD_2 | IRLZ44N gate (heater 2) | Via 100Ohm gate resistor |
| GPIO4 | CO2_SOLENOID | IRLZ44N gate (12V solenoid) | Via 100Ohm gate resistor |
| GPIO5 | FAN_CTRL | IRLZ44N gate (12V fan) | Via 100Ohm gate resistor |
| GPIO6 | PELTIER_H_BRIDGE_IN1 | L298N or BTS7960 IN1 | Peltier module 1 |
| GPIO7 | PELTIER_H_BRIDGE_IN2 | L298N or BTS7960 IN2 | Peltier module 1 |
| GPIO8 | PELTIER_H_BRIDGE_IN3 | L298N or BTS7960 IN3 | Peltier module 2 |
| GPIO9 | PELTIER_H_BRIDGE_IN4 | L298N or BTS7960 IN4 | Peltier module 2 |
| GPIO10 | PELTIER_EN_A | H-bridge enable A | PWM for power control |
| GPIO11 | PELTIER_EN_B | H-bridge enable B | PWM for power control |
| GPIO12 | SERVO_PWM | MG996R signal wire | 50Hz PWM, 5V tolerant signal |
| GPIO14 | MOTION_INTERLOCK | From Motion Ctrl GPIO14 | INPUT: HIGH=pause rocker |
| GPIO17 | CO2_UART_TX | SprintIR-6S-5 RX | 3.3V UART, 9600 baud |
| GPIO18 | CO2_UART_RX | SprintIR-6S-5 TX | 3.3V UART, 9600 baud |
| GPIO21 | I2C_SDA | BME280 SDA | 4.7kOhm pullup to 3.3V |
| GPIO22 | I2C_SCL | BME280 SCL | 4.7kOhm pullup to 3.3V |
| GPIO43 | USB_TX (UART0) | USB-C debug console | Serial monitor |
| GPIO44 | USB_RX (UART0) | USB-C debug console | Serial monitor |

### 3.2 DS18B20 Temperature Sensors (1-Wire Bus)

Two DS18B20 probes share a single 1-Wire bus on GPIO1.

```
    3.3V
     |
   [4.7kOhm]
     |
     +-----------> ESP32 GPIO1 (DS18B20_DATA)
     |
     +-----------> DS18B20 #1 DATA (probe: build plate / reservoir 1)
     |
     +-----------> DS18B20 #2 DATA (probe: reservoir 2)

   DS18B20 VDD ---> 3.3V
   DS18B20 GND ---> GND
```

**Notes:**
- Each DS18B20 has a unique 64-bit ROM address; enumerate at startup to identify probes.
- Use parasitic power mode only if cable runs exceed 3m; otherwise use normal power (VDD to 3.3V).
- Conversion time: ~750ms at 12-bit resolution. Read both sensors sequentially or issue a bus-wide convert command.

### 3.3 Silicone Heater Pads (MOSFET-Switched, 24V)

Two silicone heater pads (e.g., 50W each, 24V) are driven via N-channel MOSFETs with PWM for PID temperature control.

```
                     24V
                      |
                 [Heater Pad]
                      |
                  Drain (IRLZ44N)
                      |
  ESP32 GPIO -[100R]- Gate
                      |
                  Source --- GND
                      |
                   [10kOhm] (gate-to-source pulldown)
```

**MOSFET:** IRLZ44N (logic-level, Vgs(th) ~1.0-2.0V, Rds(on) ~0.022Ohm at Vgs=5V)
- At 3.3V Vgs, the IRLZ44N is fully on for loads up to ~5A. Confirmed suitable.
- The 100Ohm gate resistor limits inrush current and damps oscillation.
- The 10kOhm gate-to-source pulldown ensures MOSFET stays OFF when ESP32 pin is floating (during boot).

**PWM settings:**
- Frequency: 1kHz (sufficient for thermal mass of silicone pad)
- Resolution: 8-bit (0-255 duty cycle)
- PID loop runs at 1Hz sample rate (DS18B20 conversion takes ~750ms)

### 3.4 CO2 Solenoid Valve (MOSFET-Switched, 12V)

```
                     12V
                      |
                 +----+----+
                 |         |
            [Solenoid]  [1N4007]  <-- Flyback diode (cathode to 12V)
                 |         |
                 +----+----+
                      |
                  Drain (IRLZ44N)
                      |
  ESP32 GPIO4 -[100R]- Gate
                      |
                  Source --- GND
                      |
                   [10kOhm] pulldown
```

**CRITICAL: Flyback diode required.** The solenoid is an inductive load. Without the 1N4007 (or equivalent) across the solenoid, voltage spikes during turn-off will destroy the MOSFET or cause EMI resets on the ESP32.

### 3.5 SprintIR-6S-5 CO2 Sensor (UART)

```
  SprintIR-6S-5         ESP32-S3 #2
  +-----------+          +-----------+
  | TX -------|--------->| GPIO18 RX |
  | RX -------|<---------| GPIO17 TX |
  | VCC ------|--- 3.3V              |
  | GND ------|--- GND               |
  +-----------+          +-----------+
```

**Notes:**
- Default baud: 9600, 8N1
- Operating voltage: 3.0-3.6V (3.3V from ESP32 LDO is fine)
- Measurement range: 0-5% CO2 (50,000 ppm)
- Response time: < 3.5s (T90)
- Command protocol: ASCII, send `Z\r\n` for CO2 reading, `z\r\n` for filtered reading
- Warm-up time: ~30 seconds for stable readings

### 3.6 BME280 Humidity Sensor (I2C)

```
  BME280 Breakout       ESP32-S3 #2
  +-------------+        +-----------+
  | SDA --------|------->| GPIO21    |
  | SCL --------|------->| GPIO22    |
  | VCC --------|--- 3.3V            |
  | GND --------|--- GND             |
  | SDO --------|--- GND (addr 0x76) |
  +-------------+        +-----------+
        |    |
      [4.7k][4.7k]  pullups to 3.3V
        |    |
       SDA  SCL
```

**I2C Address:**
- SDO to GND: 0x76
- SDO to VCC: 0x77
- Default: 0x76

**Measurement capabilities:**
- Temperature: -40 to +85C (accuracy +/-1C)
- Humidity: 0-100% RH (accuracy +/-3%)
- Pressure: 300-1100 hPa

### 3.7 MG996R Servo (Rocker Platform)

```
  MG996R Servo           ESP32-S3 #2
  +------------+          +-----------+
  | Signal ----|<---------| GPIO12    |  (PWM, 50Hz)
  | VCC -------|--- 5V Rail (NOT 3.3V)
  | GND -------|--- GND (shared with ESP32)
  +------------+          +-----------+
```

**IMPORTANT:** The MG996R draws up to 2.5A stall current at 5V. Power it from the 5V buck converter, NOT from the ESP32 USB 5V pin (which is limited to ~500mA).

**PWM Configuration:**
- Frequency: 50Hz (20ms period)
- Pulse width: 500us (0 deg) to 2500us (180 deg)
- Use ESP32 LEDC peripheral, channel 0, 16-bit resolution
- Rocker motion: oscillate between two angles (e.g., 60 deg and 120 deg) at configurable frequency (0.5-2 Hz)

**Motion Interlock:**
- Before moving servo, check GPIO14 (MOTION_INTERLOCK)
- If HIGH: motion controller is moving the robot -- pause rocking
- If LOW: robot is idle -- safe to rock
- Debounce the interlock signal (50ms) to avoid glitches during rapid stop/start

### 3.8 Peltier Modules via H-Bridge

Two TEC1-12706 Peltier modules are driven via an H-bridge (BTS7960 recommended for current capacity, or L298N for lower-power testing).

```
  ESP32-S3 #2            BTS7960 H-Bridge #1
  +-----------+           +------------------+
  | GPIO6 IN1-|---------->| RPWM             |---> TEC1-12706 #1
  | GPIO7 IN2-|---------->| LPWM             |---> (hot/cold side
  | GPIO10 EN-|---------->| R_EN + L_EN      |     depends on polarity)
  +-----------+           | VCC --- 12V      |
                          | GND --- GND      |
                          +------------------+

  (Repeat for GPIO8/GPIO9/GPIO11 -> BTS7960 #2 -> TEC1-12706 #2)
```

**BTS7960 vs L298N:**
- BTS7960: handles 43A continuous, suitable for TEC1-12706 (6A max)
- L298N: handles 2A continuous (4A peak) -- NOT sufficient for full-power Peltier drive
- **Recommendation:** Use BTS7960 for production, L298N acceptable for low-power bench testing only

**Peltier control logic:**
- IN1 HIGH + IN2 LOW = forward polarity (one side hot, one side cold)
- IN1 LOW + IN2 HIGH = reverse polarity (swap hot/cold)
- EN pin: PWM for power modulation (PID output drives duty cycle)
- PWM frequency: 10kHz (reduces audible noise from Peltier)
- NEVER drive both IN1 and IN2 HIGH simultaneously (shoot-through)

**TEC1-12706 Specs:**
- Vmax: 12V
- Imax: 6A
- Qmax: 50W (heat pumping capacity)
- dTmax: 66C
- Requires heatsink + fan on hot side

### 3.9 Circulation Fan (MOSFET-Switched, 12V)

Same circuit as solenoid (Section 3.4) but on GPIO5:

```
                     12V
                      |
                 +----+----+
                 |         |
              [Fan]     [1N4007]  <-- Flyback diode
                 |         |
                 +----+----+
                      |
                  Drain (IRLZ44N)
                      |
  ESP32 GPIO5 -[100R]- Gate
                      |
                  Source --- GND
                      |
                   [10kOhm] pulldown
```

**Notes:**
- Fan motor is inductive -- flyback diode required
- PWM at 25kHz for silent speed control (or simple ON/OFF)

---

## 4. Inter-Controller Communication

### 4.1 Simple GPIO Interlock (Minimum Viable)

```
  Motion Controller              Environmental Controller
  ESP32-S3 #1                    ESP32-S3 #2
  +-----------+                  +-----------+
  | GPIO14 ---|------[1kOhm]--->| GPIO14    |
  | (OUTPUT)  |                  | (INPUT)   |
  | GND ------|--- shared GND --| GND       |
  +-----------+                  +-----------+
```

**Protocol:**
- Motion controller sets GPIO14 HIGH before any axis move
- Motion controller sets GPIO14 LOW after move completes and motors idle
- Environmental controller polls GPIO14 at 50ms interval
- Servo rocking pauses within 100ms of interlock going HIGH

**IMPORTANT:** Both ESP32 boards must share a common GND. The 1kOhm series resistor protects against accidental mis-configuration (both pins set as OUTPUT).

### 4.2 Optional UART Communication (Richer Protocol)

For future expansion (e.g., requesting temperature data from the motion controller, coordinating sequences):

```
  Motion Controller              Environmental Controller
  ESP32-S3 #1                    ESP32-S3 #2
  +-----------+                  +-----------+
  | GPIO15 TX-|---------------->| GPIO15 RX |
  | GPIO16 RX-|<----------------| GPIO16 TX |
  | GND ------|--- shared GND --| GND       |
  +-----------+                  +-----------+
```

- Baud: 115200, 8N1
- Simple JSON or fixed-width message protocol
- Messages: `{"cmd":"pause_rocker"}`, `{"cmd":"resume_rocker"}`, `{"cmd":"get_temp"}`, etc.

---

## 5. Complete Wiring Summary Tables

### 5.1 Motion Controller (ESP32-S3 #1) -- All Connections

| GPIO | Signal | Direction | Destination | Wire Color (suggested) |
|---|---|---|---|---|
| 1 | X_STEP | OUT | TMC2209 #1 STEP | Yellow |
| 2 | X_DIR | OUT | TMC2209 #1 DIR | Orange |
| 3 | Y_STEP | OUT | TMC2209 #2 STEP | Yellow |
| 4 | Y_DIR | OUT | TMC2209 #2 DIR | Orange |
| 5 | Z_STEP | OUT | TMC2209 #3 STEP | Yellow |
| 6 | Z_DIR | OUT | TMC2209 #3 DIR | Orange |
| 7 | I_STEP | OUT | TMC2209 #4 STEP | Yellow |
| 8 | I_DIR | OUT | TMC2209 #4 DIR | Orange |
| 9 | STEPPER_EN | OUT | All TMC2209 EN | Green |
| 10 | X_MIN | IN | Optocoupler (X limit) | White |
| 11 | Y_MIN | IN | Optocoupler (Y limit) | White |
| 12 | Z_MIN | IN | Optocoupler (Z limit) | White |
| 13 | I_MIN | IN | Optocoupler (I limit) | White |
| 14 | INTERLOCK | OUT | Env Ctrl GPIO14 | Blue |
| 15 | PROBE | IN | Z-probe (optional) | Purple |
| 17 | TMC_UART_TX | OUT | TMC2209 PDN_UART bus | Grey |
| 18 | TMC_UART_RX | IN | TMC2209 PDN_UART bus | Grey |
| 43 | USB_TX | OUT | USB debug | -- |
| 44 | USB_RX | IN | USB debug | -- |

### 5.2 Environmental Controller (ESP32-S3 #2) -- All Connections

| GPIO | Signal | Direction | Destination | Wire Color (suggested) |
|---|---|---|---|---|
| 1 | DS18B20_DATA | I/O | 2x DS18B20 (1-Wire) | Red |
| 2 | HEATER_1 | OUT | IRLZ44N gate (heater pad 1) | Brown |
| 3 | HEATER_2 | OUT | IRLZ44N gate (heater pad 2) | Brown |
| 4 | CO2_SOLENOID | OUT | IRLZ44N gate (12V solenoid) | Brown |
| 5 | FAN_CTRL | OUT | IRLZ44N gate (12V fan) | Brown |
| 6 | PELTIER_IN1 | OUT | BTS7960 #1 RPWM | Orange |
| 7 | PELTIER_IN2 | OUT | BTS7960 #1 LPWM | Orange |
| 8 | PELTIER_IN3 | OUT | BTS7960 #2 RPWM | Orange |
| 9 | PELTIER_IN4 | OUT | BTS7960 #2 LPWM | Orange |
| 10 | PELTIER_EN_A | OUT | BTS7960 #1 R_EN+L_EN | Yellow |
| 11 | PELTIER_EN_B | OUT | BTS7960 #2 R_EN+L_EN | Yellow |
| 12 | SERVO_PWM | OUT | MG996R signal | White |
| 14 | INTERLOCK | IN | Motion Ctrl GPIO14 | Blue |
| 17 | CO2_TX | OUT | SprintIR-6S-5 RX | Green |
| 18 | CO2_RX | IN | SprintIR-6S-5 TX | Green |
| 21 | I2C_SDA | I/O | BME280 SDA | Violet |
| 22 | I2C_SCL | OUT | BME280 SCL | Violet |
| 43 | USB_TX | OUT | USB debug | -- |
| 44 | USB_RX | IN | USB debug | -- |

---

## 6. Safety Notes

### 6.1 Flyback / Snubber Protection

Every inductive load (solenoid, fan motor, relay coil) MUST have a flyback diode:

| Component | Diode | Placement |
|---|---|---|
| CO2 solenoid valve | 1N4007 | Across solenoid, cathode to +12V |
| 12V circulation fan | 1N4007 | Across motor, cathode to +12V |
| Any relay coils | 1N4007 | Across coil, cathode to +V |

Failure to install flyback diodes will result in voltage spikes that can destroy MOSFETs and cause ESP32 resets.

### 6.2 MOSFET Gate Protection

All MOSFET gates must have:
- **100 Ohm series resistor** on the gate line (limits current, damps oscillation)
- **10 kOhm pulldown resistor** from gate to source (ensures OFF state during ESP32 boot when GPIOs are floating/high-Z)

Optional but recommended:
- **15V Zener diode** from gate to source (clamps gate voltage, protects against ESD)

### 6.3 ESP32-S3 Boot Pin Considerations

Some ESP32-S3 GPIOs have special behavior during boot. Avoid using these for MOSFET gates (where an unintended HIGH during boot could activate a heater or solenoid):

| GPIO | Boot Behavior | Safe for MOSFET? |
|---|---|---|
| GPIO0 | Strapping pin (boot mode) | NO -- avoid |
| GPIO3 | Strapping pin (JTAG) | Use with caution |
| GPIO45 | Strapping pin (VDD_SPI) | NO -- avoid |
| GPIO46 | Strapping pin (boot mode) | NO -- avoid |
| GPIO19/20 | USB D-/D+ | NO -- reserved for USB |

The pin assignments in this document avoid all boot-sensitive GPIOs for safety-critical outputs.

### 6.4 Thermal Protection

- **Heater pads:** Implement software thermal runaway protection. If temperature exceeds setpoint + 10C, cut PWM to zero and flag an error.
- **Peltier modules:** Hot side temperature must not exceed 80C. Monitor via DS18B20 or thermistor on heatsink.
- **TMC2209:** Internal thermal shutdown at ~150C. Enable UART thermal monitoring in FluidNC.
- **All MOSFETs switching >2A:** Use heatsink or copper pour on PCB under drain pad.

### 6.5 Grounding

- **Star grounding** from the 24V PSU ground terminal. Do not daisy-chain grounds between high-current loads.
- Stepper motor GND and heater GND should be separate runs back to the PSU.
- ESP32 signal GND and power GND must be tied together at a single point (star).
- Keep 3.3V logic wires away from 24V power wires. Use separate cable harnesses.

### 6.6 EMI / Noise

- Use **shielded cable** for limit switch wires (per OTTO design)
- Add **100nF ceramic capacitor** close to each TMC2209 VM pin (bulk decoupling)
- Add **100uF electrolytic** on the 24V input to the stepper driver cluster
- Add **10uF + 100nF** on each ESP32 3.3V rail (close to VCC pins)
- Keep UART wires (TMC, CO2 sensor) short (< 30cm) or use twisted pair

---

## 7. Bill of Materials (Key Components)

| Qty | Component | Specifications | Notes |
|---|---|---|---|
| 2 | ESP32-S3 DevKitC-1 | N16R8 (16MB flash, 8MB PSRAM) | USB-C, dual-core 240MHz |
| 4 | TMC2209 Stepper Driver | UART mode, Rsense 0.11 Ohm | BTT or Fysetc modules |
| 4 | NEMA 17 Stepper Motor | 1.5A, 1.8 deg, 40mm body | 42BYGHW811 or equivalent |
| 4 | PC817 Optocoupler | CTR > 50%, 4-pin DIP | For limit switch isolation |
| 4 | Mechanical Limit Switch | NC contact, lever actuator | Omron D2F-L or equivalent |
| 4 | IRLZ44N N-MOSFET | Logic-level, Vgs(th) 1-2V, 47A | TO-220 package |
| 2 | DS18B20 | Waterproof probe, 1m cable | Stainless steel tip |
| 2 | Silicone Heater Pad | 24V, 50W, sized to reservoir | Adhesive backing |
| 1 | SprintIR-6S-5 | CO2 sensor, 0-5%, UART | 3.3V, ~35mA |
| 1 | BME280 Breakout | I2C, 3.3V | GY-BME280 or Adafruit |
| 1 | MG996R Servo | Metal gear, 10kg-cm torque | 5V power rail |
| 2 | TEC1-12706 | Peltier module, 12V, 6A, 50W | 40x40mm |
| 2 | BTS7960 H-Bridge Module | 43A, dual half-bridge | For Peltier direction control |
| 1 | 12V Solenoid Valve | Normally closed, 1/4" barb | CO2 gas line |
| 1 | 12V DC Fan | 80mm or 120mm, brushless | Enclosure circulation |
| 1 | 24V PSU | 15A, 360W, enclosed | Mean Well LRS-350-24 |
| 2 | LM2596 Buck Converter | Adjustable, 3A | One set to 12V, one to 5V |
| 1 | AMS1117-3.3 LDO | 3.3V, 1A, SOT-223 | If not using ESP32 onboard reg |
| 8 | 1N4007 Diode | 1A, 1000V | Flyback protection |
| 4 | 4.7kOhm Resistor | 1/4W | I2C and 1-Wire pullups |
| 4 | 100 Ohm Resistor | 1/4W | MOSFET gate series |
| 4 | 10kOhm Resistor | 1/4W | MOSFET gate pulldown |
| 1 | 1kOhm Resistor | 1/4W | TMC UART TX series |
| -- | Blade Fuses + Holders | 5A, 6A, 8A, 15A | Inline, per power branch |
| -- | 100nF Ceramic Caps | MLCC, 50V | Bulk decoupling, 10+ pcs |
| -- | 100uF Electrolytic | 50V | 24V input bulk cap |
| -- | Wago 221 Connectors | 2/3/5 port | Inline wire-to-wire |
| -- | JST-XH Connectors | 2/3/4 pin | Sensor and signal cables |
| -- | XT60 Connectors | 60A rated | 24V power distribution |
| -- | 18 AWG Silicone Wire | Red/Black | Power distribution (24V) |
| -- | 22 AWG Hookup Wire | Assorted colors | Signal wires |
| -- | Shielded Cable | 2-conductor | Limit switch runs |
| -- | Cable Glands | PG7 / PG9 | If using enclosure |

---

## 8. FluidNC Configuration Reference

Relevant FluidNC YAML snippet for the motion controller pin mapping:

```yaml
board: LaminarForge Motion Controller
name: LaminarForge

stepping:
  engine: RMT
  idle_ms: 250
  dir_delay_us: 1
  pulse_us: 4
  disable_delay_us: 0

uart1:
  txd_pin: gpio.17
  rxd_pin: gpio.18
  baud: 115200
  mode: 8N1

axes:
  shared_stepper_disable_pin: gpio.9

  x:
    steps_per_mm: 80.0
    max_rate_mm_per_min: 5000
    acceleration_mm_per_sec2: 200
    max_travel_mm: 300
    homing:
      cycle: 1
      mpos_mm: 0
      positive_direction: false
    motor0:
      tmc_2209:
        uart_num: 1
        addr: 0
        r_sense_ohms: 0.110
        run_amps: 1.000
        hold_amps: 0.500
        microsteps: 16
        stallguard: 10
      step_pin: gpio.1
      direction_pin: gpio.2

  y:
    steps_per_mm: 80.0
    max_rate_mm_per_min: 5000
    acceleration_mm_per_sec2: 200
    max_travel_mm: 200
    homing:
      cycle: 2
      mpos_mm: 0
      positive_direction: false
    motor0:
      tmc_2209:
        uart_num: 1
        addr: 1
        r_sense_ohms: 0.110
        run_amps: 1.000
        hold_amps: 0.500
        microsteps: 16
        stallguard: 10
      step_pin: gpio.3
      direction_pin: gpio.4

  z:
    steps_per_mm: 400.0
    max_rate_mm_per_min: 2000
    acceleration_mm_per_sec2: 100
    max_travel_mm: 100
    homing:
      cycle: 3
      mpos_mm: 0
      positive_direction: true
    motor0:
      tmc_2209:
        uart_num: 1
        addr: 2
        r_sense_ohms: 0.110
        run_amps: 1.000
        hold_amps: 0.500
        microsteps: 16
        stallguard: 10
      step_pin: gpio.5
      direction_pin: gpio.6

  i:
    steps_per_mm: 200.0
    max_rate_mm_per_min: 1000
    acceleration_mm_per_sec2: 50
    max_travel_mm: 50
    homing:
      cycle: 4
      mpos_mm: 0
      positive_direction: false
    motor0:
      tmc_2209:
        uart_num: 1
        addr: 3
        r_sense_ohms: 0.110
        run_amps: 1.000
        hold_amps: 0.500
        microsteps: 16
        stallguard: 10
      step_pin: gpio.7
      direction_pin: gpio.8

control:
  safety_door_pin: NO_PIN

coolant:
  flood_pin: gpio.16

probe:
  pin: gpio.15:low:pu
```

---

## 9. Assembly Checklist

Before powering on:

- [ ] Verify 24V PSU output with multimeter (no load)
- [ ] Verify 12V buck output (adjust trimpot)
- [ ] Verify 5V buck output (adjust trimpot)
- [ ] Check all flyback diodes are installed with correct polarity (cathode band toward +V)
- [ ] Check MOSFET gate pulldown resistors are installed
- [ ] Verify TMC2209 MS1/MS2 address pins match the table in Section 2.1
- [ ] Verify TMC2209 VREF or UART current settings before connecting motors
- [ ] Connect stepper motors one at a time; verify rotation direction
- [ ] Test each limit switch triggers correctly (check with `$Limits` in FluidNC console)
- [ ] Test DS18B20 sensors enumerate with correct addresses
- [ ] Test heater pad MOSFET switching (low duty cycle first, monitor temperature)
- [ ] Test CO2 sensor UART communication (send `Z\r\n`, expect numeric response)
- [ ] Test BME280 I2C communication (scan address 0x76)
- [ ] Test servo range of motion at low speed
- [ ] Test Peltier polarity (feel hot/cold sides, verify direction control)
- [ ] Test inter-controller interlock (assert HIGH, verify env controller pauses)
- [ ] Run full homing cycle at reduced speed
- [ ] Monitor all temperatures during 30-minute burn-in test

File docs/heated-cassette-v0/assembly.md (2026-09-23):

# Assembly handbook - LF-CAS-V0 Rev D

## Mechanical hardware to order

All ordinary machine screws below are A2-70 stainless socket caps, ISO 4762, coarse metric threads. Buy several spares. Thread lengths are under the head. Do not substitute longer screws without checking bottoming and interference.

| Quantity | Item | Use |
|---:|---|---|
| 6 | M3x14 | Roof to side plates |
| 4 | M3x10 | Bezel to side plates, recessed heads |
| 4 | D3 m6 x10 dowel | Side to roof, 6 mm insertion |
| 2 | D3 m6 x10 dowel | Side to bezel, 6 mm insertion |
| 6 | M3x40 | Risers and guide rails into housing |
| 4 | M3x12 | Rear cover |
| 3 | M3x14 | Front flange to drawer |
| 8 | M3x14 | Heater guards through 8 mm spacers |
| 4 | M2x5 | Plate nest |
| 2 | M2x4 | Gasket shim ears |
| 4 | M3x8 | Moving and fixed cable bracket bases |
| 4 | M2x12 | Cable clamp jaws |
| 2 | M3x6 with M3 flat washer | Thermostat tabs, inspect assembled engagement |
| 1 | M5x8 socket set screw | Close temporary probe port when unused |
| 1 | PTFE tube, 4 mm OD / 2 mm ID, 10 mm length | Removable probe-wire sleeve through front flange |
| 1 | Accu SKH-M2-10-A2 | Diameter 3 x 10 shoulder, M2x0.4 x 3.8 thread, diameter 5 x 2 head |
| 2 | Elesa BT.12 p-M4x16, code 6342 | Manual closure knobs |
| 2 | Keenovo 12073, variant 33194097803404 | 24 V, 60 W, 100 x 100 mm heater |
| 2 | Omega SA1-RTD | 3-wire Pt100, 1 m stripped leads |
| 2 | Sensata 67L050 | NC temperature cutoffs; electrical BOM includes these |
| 1 set | BF-1000 gasket, 9731 PSA, measured backing stack | Front seal |
| 1 set | A160-T-010-0500-G tape profiles | Six guide strips |
| 1 each | Greiner 655101 and 656101 lid | Water-test plate and lid |

Heaters, RTDs and cutoffs also appear in the electrical BOM: order two total of each, not four. Guard spacers are eight aluminum sleeves, diameter 6 / bore 3.4 / length 8.0 +/-0.10; plain uncoated tube cut and faced to length is acceptable. Use the exact CAD/stock kit for other custom parts.

Reference links: https://www.accu.co.uk/knurled-socket-shoulder-screws/49839-SKH-M2-10-A2 ; https://www.elesa.com/en/elesab2bstoreus/Clamping-knobs--Knurled-knobs--BT-p . Confirm Elesa M4x16 variant at order time.

## Incoming checks

Check the shop's finished-dimension report, threaded holes, flat stop faces and burr-free cable edges. Dry-fit the delivered plate and lid inside the 26 mm object-height allowance. Check actual pad/PSA thickness and lead bump: the space beneath each guard is 8 mm. Accept no protrusion above 6 mm in that space, leaving at least 2 mm clearance. Route tall joints out through the rear notch, not under a guard screw.

Check each heater resistance at room temperature: at least 9.0 ohms, no conductor-to-metal short. Confirm the three-wire Pt100 lead pair by resistance, and confirm the 67L050 contact is closed at room temperature. The heater's embedded NTC pair is unused: insulate the two wires separately.

## 0. Assemble the Rev D frame

Finish-ream the side D3 H7 locating bores after anodizing. Use D3 m6 dowels: this is a transition fit, so do not assume every pin is a press fit. If loose, retain the side end with a suitable retaining compound per its manufacturer instructions; keep the mating plate slip bores clean. Roof and bezel bores are D3.15 +0.02/0 to accommodate the specified +/-0.025 coordinate tolerance. Seat roof pins 6 mm into sides; fit roof and tighten six M3x14 screws evenly. Seat front pins 6 mm into sides; their ends sit nominally 2 mm below the assembled bezel front. Fit bezel with four M3x10 screws; all heads must be below the front seal face. Assemble on a flat surface, measure guide spacing and diagonals, and verify the loaded drawer moves freely cold and at 37 C. Reject binding, rocking joints, exposed front fastener heads or pins, and any seal-face step. The joints are not pressure seals.

## 1. Bond the two heaters and sensors

The pad land is centered at X=0, Y=59.99: X=-50..50, Y=9.99..109.99. Housing heater bonds to Z=53.225; drawer heater bonds to its underside Z=7.225. Leads point rearward. Clean the bare masked lands as the adhesive manufacturer specifies, apply without air bubbles, and allow its required bond dwell before cycling heat.

Each RTD carrier bonds directly to its aluminum zone in the 30 x 25 mm land X=-20..10, Y=116.73..141.73. It does not sit on the heater. Locate the thermostat tab at X=25, Y=136.73 on the same zone; use M3x6 plus a flat washer. The tab must contact metal. Check screw length against the supplied tab/washer stack and that it neither bottoms nor projects above the plate-support face. Use a shorter screw if measured engagement would violate that envelope; minimum engagement 3 mm.

Dress RTD and thermostat leads separately from heater power joints. Use heat-rated sleeving on exposed joints. Strain-relieve the leads on the heated assembly; no solder splice belongs in the moving bend. Keep all components below the guard's 6 mm accepted stack limit. Record sensor and heater serial/lot identifiers.

## 2. Install guide tape, rails and risers

Apply the six cut tape pieces to clean dry guide edges; plate contact remains the aluminum drawer surface, with its specified anodized finish. Left lower has stop access; left upper begins Y=22. No folded edge, adhesive squeeze-out or overlapping tape. Measure installed thickness and assemble within the guide acceptance ranges.

Fit rails and risers with six M3x40 screws, heads in the underside counterbores. Starting assembly torque is 0.3 N m, an engineering bench limit rather than a supplier fastener rating. Seat evenly and verify a flat base. Reduce torque if thin parts distort; do not use tightening to pull a crooked rail into alignment. All M3 structural joints use this initial limit unless a component manufacturer specifies otherwise.

## 3. Fit drawer, flange, stop and nest

Attach the front flange with three M3x14 screws. Slide the drawer in without the gasket, confirming free travel and the closed front stop. Through the left rail's diameter 6 access, install the SKH-M2-10-A2 shoulder screw into the housing receiver. Its 10 mm shoulder seats against the fixed guide roof and passes through the drawer slot. It must not clamp the drawer. Do not substitute a fully threaded screw.

Fit the nest with four M2x5 screws. Initial M2 seating torque is at most 0.08 N m, subject to free movement and no distortion. Check the plate drops into and lifts from the nest without binding. Check nominal full travel of 107.73 mm and stop retention. Never pull violently against the stop.

## 4. Fit the face gasket

Select and measure the foam/adhesive/shim stack using the manufacturing-note formula. Bond foam to the shim ring with 9731, leaving ears clear. Fit the stack into the groove and retain the ears with M2x4 screws. Verify the heads sit inside the mating flange relief pockets.

Install the two closure knobs. Close by hand, alternating knobs until the flange seats on its metal stop. Use fingers only; do not use pliers or a lever. Verify continuous light contact around the full ring and free release during opening. Uneven marks mean a stack/flatness problem, not a reason to apply more torque. A paper-strip contact check is sufficient for this draft seal; no pressure-tight test.

## 5. Fit guards and cable brackets

Install each guard on four 8 mm spacers with M3x14 screws. Keep leads clear of the spacer faces and exit through the notch. The moving bracket attaches beneath the drawer at X=-42/-28, Y=146.73 with two M3x8 screws. The fixed bracket attaches beneath the rear cover at X=28/42, Y=165.73 with two M3x8 screws. Fit the rear cover with four M3x12 screws. Confirm no fastener tip reaches a plate/contact surface.

Clamp the 6 mm power jacket in the lower groove centered Z=-18 and the 5.5 mm signal jacket in the upper groove Z=-9. The M2x12 jaw screws tighten evenly. Nominal groove diameters are 5.8 and 5.3 mm; accept only if the delivered jackets fit without cutting, flattening conductors or losing grip. The final clamp is a prototype strain relief, not a cable-maker crush certification. Mark the jacket at each clamp to reveal slipping.

## 6. Route the moving harness

Use igus CF9-10-03 power and CF9-02-06 signal cable. Both exit the REAR faces of their clamps toward +Y, in separate horizontal planes. Moving center X=-35, fixed X=+35. Cut 250 mm free centerline length between rear clamp faces, excluding the 20 mm gripped portions at each end. Add the required static tails; buy at least 2 m of each cable for prototype tails and service loops, then cut to the actual controller-box position.

Shape each loop into two straight legs joined by a 35 mm-radius semicircle bowing rearward. At closed position, the arc ends are at Y=226.752 and its rear centerline reaches Y=261.752. At full extension these become 172.887 and 207.887. The fixed straight leg remains 16.157 mm. The largest cable outside surface reaches approximately Y=264.752.

Reserve X=-45..45, Z=-24..-3 and Y=49..270 as the underbody/rear moving-harness corridor. Keep tools, shelves, other cables and the controller box out. The two loop planes are 9 mm apart; keep them separate. Actual cables can sag/twist: cycle the full stroke by hand and inspect this space before applying power. This free-loop V0 has no production flex-life rating.

## 7. Assemble and wire the controller box

Use the selected enclosure and the final control-box drilling sheet. Mount PIDs in the FRONT BASE wall, not on the lid. Keep their rear bodies/clips clear of the panel and DIN devices. Mount SSRs to the metal panel; apply manufacturer torque values from the electrical schedule. The external enclosed brick carries all mains connections.

Wire exactly to the terminal schedule and schematic. The PIDs receive regulated 13.0 V from DDR-15G-12, not the nominal 24 V brick. Use DC-output SSRs. The relay coils have polarity-sensitive diodes. Label every terminal and connector before powering. Make heater-side connectors dead before disconnecting them.

Micro-Fit contacts accept 20-24 AWG; use the specified transition pigtails for 1 mm2 power cable and the RTD's finer factory wires. Do not cut away strands to fit a contact. Keep all transitions outside flexible bends. Use equal three-wire RTD extension lengths and gauges. Roof and drawer connectors must carry durable zone labels.

## 8. Commission before loading water

Follow the electrical inspection and fault-test sequence, then the water-temperature protocol. Keep prototype operation attended until those tests pass. Record actual controller values, sensor calibration corrections, gasket shim stack, currents and temperatures in the commissioning log.

This cassette can later be mounted to a rocking shelf, but the V0 bench feet are not a rocker. A later shelf must support both risers, secure the cassette, retain the plate/lid and preserve cable clearances through tilt. No angle is assumed for an unselected tissue plate.

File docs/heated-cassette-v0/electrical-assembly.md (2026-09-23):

# Heated cassette V0: selected electrical assembly and terminal schedule
Rev D component selection and terminal schedule, 2026-09-13. Read with the final control-box drilling layout and mechanical assembly handbook. No purchases or physical commissioning have been performed.

## Selected architecture
Two independent 24 V resistive heaters, each controlled by a standalone Pt100 PID and DC-output SSR. Each heater also has a separate metal-mounted, normally-closed bimetal thermostat controlling a manually latched electromechanical power relay. The brick contains all mains wiring. A shared red STOP drops both heater relays; green RESET buttons arm zones separately. Controllers remain powered when heaters are stopped.

A 50°C nominal thermostat is not a precise 50°C maximum: its tolerance permits operation at 55°C, with additional mounted thermal lag. This cutoff protects against runaway, not sample-temperature excursion. Actual media temperature needs immersion-probe validation.

## Exact BOM
Prices are observed USD unit prices, excluding tax/shipping; unverified prices are explicitly not quotes. Counts are for two zones.

|Qty|Reference|Manufacturer/orderable part|Selection and sourcing|
|---:|---|---|---|
|2|H1,H2|Keenovo 12073; variant 33194097803404|24 V, 60 W, 100×100 mm silicone pad with 3M PSA and embedded NTC; $27.74 each from manufacturer public variant data.|
|2|T1,T2|Omega SA1-RTD|Three-wire Pt100 Class A, 1 m leads; carrier 25×19 mm. Price not verified.|
|2|C1,C2|Auber SYL-2L52|12–24 V AC/DC supply, Pt100 input, SSR drive; $46.50 each. Do not order triac version SYL-2L72.|
|2|Q1,Q2|Carlo Gavazzi RM1D060D10|10 A DC-output SSR, load 1–60 VDC, control 4–32 VDC; $57 each, 191 shown in stock.|
|2|TH1,TH2|Sensata/Airpax 67L050|NC, opens nominal 50°C; 519 stock shown, single-piece price not verified. Do not substitute 67F050, which closes on rise.|
|2|K1,K2|Omron G2R-2-SD DC24(S)|DPDT relay with integral coil diode; $16.28 each, 150 stock shown.|
|2|XK1,XK2|Omron P2RF-08-PU|Push-in DIN socket for selected relay; price not verified.|
|1|PS1|Mean Well GST160A24-R7B|Enclosed external 24 V, 160 W, 6.67 A brick, C14 inlet; $52.40.|
|1|AC1|Mean Well YP12_YC12|US NEMA5-15P to IEC C13 cord, 6 ft; $7.29 observed related listing.|
|1|J0|Kycon KPJX-PM-4S|Panel-mount mating 4-position power DIN socket, 48 VDC/7.5 A; $2.45 observed related listing.|
|1|DC1|Mean Well DDR-15G-12|DIN converter, 9–36 V input; adjust output to 13.0 V before attaching controllers. Price not verified.|
|2|S1,S2|Schneider XB5AA31|Green spring-return NO reset button.|
|1|S0|Schneider XB5AA42|Red spring-return NC stop button; this is a heater-stop function, not a certified emergency-stop system.|
|1|F0|Littelfuse 028707.5PXCN|7.5 A ATOF main positive fuse.|
|2|F1,F2|Littelfuse 0287004.PXCN|4 A ATOF heater branch fuses.|
|1|F3|Littelfuse 0287001.PXCN|1 A ATOF control branch fuse.|
|4|XF0–XF3|Littelfuse FHAC0001ZXJ|Inline covered ATO holder, 32 VDC/20 A, 16 AWG leads.|
|1|E1|Hammond 1554YA2GY|300×240×120 mm enclosure.|
|1|P1|Hammond 1554YPL|Matching inner mounting panel.|
|1|R1|Omron PFP-50N|500 mm stock; cut one 220 mm rail to the final layout.|
|2|ES1–2|Omron PFP-M|DIN end stops.|
|1 set|X nodes|Nine Wago 221-413, three 221-415, six carriers 221-500|Separate-potential splice groups per final layout.|
|4|CG1–4|Hammond 1427NCGM12B|M12 cable glands for four cable entries; individual PDF gives3–6.5mm cable range, locknut/o-ring included.|
|2 lengths|WP1,WP2|igus CF9-10-03|3×1mm² cable, approximate6mm OD; two numbered cores carry heater current, green/yellow spare insulated.|
|2 lengths|WS1,WS2|igus CF9-02-06|6×0.25mm² signal/cutoff cable, approximate5.5mm OD.|
|2 each|JP housings|Molex430250200 /430200201|Two-position power connector pair per zone.|
|2 each|JS housings|Molex430250600 /430200601|Six-position signal/cutoff pair per zone, five circuits populated.|
|14 each|Crimp contacts|Molex430300007 /430310007|Female/male20–24AWG; power uses20AWG transition pigtails, sensor24AWG.|
|1|TIM|Electrolube HTS02S|Thin thermal compound at SSR mounting interfaces, as permitted in SSR guidance.|

Heaters: [manufacturer selected variant](https://keenovo.store/products/keenovo-square-silicone-heater-3d-printer-build-plate-heatbed-heating-pad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). RTD geometry: [Omega drawing](https://assets.omega.com/pdf/test-and-measurement-equipment/temperature/sensors/rtds/SA1-RTD.pdf). Controller price: [Auber product](https://www.auberins.com/index.php?main_page=product_info&products_id=601). SSR price/stock: [DigiKey](https://www.digikey.com/en/products/detail/carlo-gavazzi-inc/RM1D060D10/13277977). Relay price/stock: [DigiKey](https://www.digikey.com/en/products/detail/omron-automation-and-safety/G2R-2-SD-DC24-S/1789761). Thermostat stock: [DigiKey](https://www.digikey.com/en/products/detail/sensata-airpax/67L050/1631970). Supply price: [DigiKey](https://www.digikey.com/en/products/detail/mean-well-usa-inc/GST160A24-R7B/7703602).

Verified priced subtotal for pads, PIDs, SSRs, relays, brick, cord and inlet is $357.18; this is not the total build cost. Sensors, sockets, converter, switches, protection, enclosure and harness add to it. Do not describe the full electrical package as a $55 heater system.

## Manufacturer pin references
These are physical terminal designations, not inferred wire colors. PDF page numbers below are one-based.

- C1/C2: 9/10 power; 3/4 same-end RTD leads, 5 opposite-end; 7 positive SSR drive, 8 negative. Alarm terminals 1/13/14 and unused terminals remain unwired. [Auber low-voltage supplement, p1 Fig2 and p2 RTD instructions](https://www.auberins.com/images/Manual/syl_24v_manual.pdf).
- Q1/Q2: load 1 positive, 2 negative; control 3/A1 positive, 4/A2 negative. Control demand below 16 mA is within controller drive capability. [RM1D, pp4,6,19](https://www.gavazziautomation.com/fileadmin/images/PIM/DATASHEET/ENG/SSR_RM1D.pdf).
- K1/K2 socket: A1 equals relay pin8 positive; A2 equals pin1 negative. Contact 11/pin3 common, 14/pin4 NO, 12/pin2 NC; second contact 21/pin6 common, 24/pin5 NO, 22/pin7 NC. Observe coil polarity because diode is integral. [Omron, p9 relay diagrams, p11 socket drawing](https://assets.omron.eu/downloads/latest/datasheet/en/j226_g2r-_-s_(s)_general-purpose_relay_datasheet_en.pdf).
- PS1 plug numbering: R7B1/4 positive,2/3 negative. KyconJ0 uses different numbering: inferred jack1/3 positive,2/4 negative. Before joining ANY pairs, measure the four separate jack tails with the actual brick. Wire measured-positive tails to XRAW and measured-negative tails to X0, using equal-length18AWG pigtails. [GST160A p3](https://www.meanwell.com/Upload/PDF/GST160A/GST160A-SPEC.PDF); [Kycon mating jack drawing](https://www.kycon.com/Catalog_PDF/KPJX-PM.pdf).
- DC1: terminal4 +Vin, 3 −Vin, 1 +Vout, 2 −Vout. Output adjustment range 9–13.2 V; use 13.0 V to avoid the controller's 12 V minimum and the brick's possible >24 V output. [DDR-15 pp2,5](https://www.meanwell.com/Upload/PDF/DDR-15/DDR-15-SPEC.PDF).
- S1/S2 use their NO block, marked13/14; S0 uses NC21/22. Confirm supplied contact-block markings and continuity before wiring. [Green button](https://www.se.com/us/en/product/XB5AA31/push-button-harmony-xb5-plastic-flush-green-22mm-spring-return-unmarked-1no/), [red button](https://www.se.com/us/en/product/XB5AA42/push-button-harmony-xb5-plastic-flush-red-22mm-spring-return-unmarked-1nc/).

## Complete internal terminal schedule
R=roof, D=drawer. Repeat zone rows for i=1/roof and i=2/drawer. Each named X node is one common-potential Wago splice; if more than five endpoints are needed, bridge two 5-way splices with the same gauge as the feeder. One conductor per port. Do not put distinct circuit potentials in the same splice.

|Net|From|To|Wire/termination|
|---|---|---|---|
|Raw +24|J0 measured-positive pair (drawing inference:1,3)|XRAW; XRAW→F0 input|Two equal18AWG inlet pigtails;16AWG main lead|
|Protected +24|F0 output|X24: F1 input, F2 input, F3 input|16AWG fixed distribution|
|24V return|J0 measured-negative pair (drawing inference:2,4)|X0: Q1/2 load terminal2, DC1 terminal3, K1/K2 A2|Equal18AWG inlet pigtails;16AWG distribution,1mm² SSR branches,.5mm² controls|
|Control +24|F3 output|XC: DC1 terminal4 and S0 terminal21|.5mm²|
|Control return|DC1 terminal3|X0|.5mm²|
|PID +13|DC1 terminal1|X13: C1 terminal9, C2 terminal9|.5mm²|
|PID return|DC1 terminal2|XC0: C1 terminal10, C2 terminal10|.5mm²; do not join XC0 to X0|
|Stop-permitted|S0 terminal22|XS: TH1 leadA and TH2 leadA through respective harnesses|.5mm²|
|Zone thermal return|THi leadB through harness|XLi: Si terminal13 and Ki socket21|.5mm²|
|Zone arm|Si terminal14|XAi: Ki socket24 and Ki A1|.5mm²|
|Zone coil return|Ki A2|X0|.5mm²|
|Heater branch|Fi output|Ki socket11|1mm²|
|Enabled heater feed|Ki socket14|Zone heater-positive harness→Hi power leadA|1mm² fixed; moving section per harness specification|
|Switched heater return|Hi power leadB→zone return harness|Qi load terminal1 positive|1mm² at SSR terminal|
|SSR low side|Qi load terminal2 negative|X0|1mm²|
|SSR command +|Ci terminal7|Qi control3/A1+|.5mm²|
|SSR command −|Ci terminal8|Qi control4/A2−|.5mm²|
|RTD red1|Ti first red lead via dedicated harness core|Ci terminal3|Equal-gauge three-wire RTD extension|
|RTD red2|Ti second red lead via dedicated harness core|Ci terminal4|Do not common with other red except through sensor's factory junction|
|RTD white|Ti white lead via dedicated harness core|Ci terminal5|No connection to either supply return|
|Unused|Ki12/22; Ci unused terminals; heaterNTC pair|Insulate and leave unconnected|NTC wires individually insulated, not shorted|

Inline holders are nonpolar; identify input/output labels in the built harness. Physical low-side SSR polarity is important even though the heater is nonpolar. Do not substitute an AC-output SSR.

The circuit is:
F3→STOP(NC)→THi(NC)→[RESETi(NO) parallel Ki21–24(NO)]→Ki coil→0V.
Separate power path is F0→Fi→Ki11–14(NO)→heater→Qi→0V.
A thermostat opening drops Ki even with a failed-short SSR. Cooling cannot relatch Ki with RESET released. A broken thermostat wire also drops Ki. On ordinary power removal/restoration, heaters remain disabled until each RESET is pressed. This economical circuit is not an anti-tie-down or monitored safety relay: holding RESET during restoration can rearm, and welded Ki contacts are not detected. Label RESET “release after pressing”; disconnect the brick for service. No claim of redundant fault tolerance or thermal/electrical certification is made.

## Harness boundary and terminations
Use separate Micro-Fit3.0 connectors at each zone's fixed service point, outside the moving bend. For two zones order2×Molex430250200 receptacle housings and2×430200201 plug housings for power;2×430250600 receptacles and2×430200601 plugs for signals. Use14×430300007 female contacts and14×430310007 male contacts for the seven populated circuits per zone; buy spares. Female-contact receptacles are on the control-box/supply side. Six-position cavity6 is unpopulated and insulated. Both housing pairs are polarized/latching, but roof and drawer use identical pairs: label them clearly.

|Interface cavity|Control-box endpoint|Cassette endpoint|
|---|---|---|
|JP1/JP2 cavity1|Ki socket14|Hi power leadA|
|JP1/JP2 cavity2|Qi load1+|Hi power leadB|
|JS1/JS2 cavity1|Ci terminal3|RTDred1|
|JS1/JS2 cavity2|Ci terminal4|RTDred2|
|JS1/JS2 cavity3|Ci terminal5|RTDwhite|
|JS1/JS2 cavity4|XS afterSTOP|THi leadA|
|JS1/JS2 cavity5|XLi beforeRESET/latch|THi leadB|
|JS1/JS2 cavity6|Unpopulated|Unpopulated|

Cavity numbering is the molded housing numbering; do not infer pin1 from a front-view sketch that may mirror the wire-entry view. Continuity-check each mated pair before power.

[Power receptacle](https://www.molex.com/en-us/products/part-detail/430250200), [power plug](https://www.molex.com/en-us/products/part-detail/430200201), [signal receptacle](https://www.molex.com/en-us/products/part-detail/430250600), [signal plug](https://www.molex.com/en-us/products/part-detail/430200601), [female contact](https://www.molex.com/en-us/products/part-detail/430300007), [male contact](https://www.molex.com/en-us/products/part-detail/430310007).

Selected contacts accept20/22/24AWG, insulationOD≤1.85mm, and are tin plated. They do NOT accept1mm² cable or Omega26AWG directly. At every power contact use a short≤100mm20AWG stranded copper pigtail with insulationOD≤1.85mm, rated≥80°C, transitioning by individually insulated, strain-relieved solder splice to the1mm² cable. At RTD contacts transition factory26AWG to equal24AWG pigtails; CF9-02-06 is catalogued24AWG and can enter the contact only if its actual core insulationOD fits. Keep every transition outside the flex bend. Do not remove conductor strands to fit a contact. Inspect/crimp with tooling qualified for these exact contacts; neither a universal plier nor soldering into the crimp barrel is specified. The7A per-contact catalog maximum is not a full-harness rating; verify≤2.75A normal heater operation and4A branch protection with actual20AWG pigtails, bundle and ambient.

Four Hammond1427NCGM12B glands enter E1, one power and one signal cable per zone. Use igusCF9-10-03 power cable's two numbered black cores for heater feed/return; green/yellow is insulated unused. Sleeve CF9-02-06 cores1–5 to match JS1–5 and leave core6 insulated. Record actual color mapping on both ends. Never merge RTD and heater returns. No live disconnection is specified; remove brick power before separating any connector.

Both selected cables support moving radius5×OD; R35mm covers6mm and5.5mm nominal OD. Keep actual cable minimum radius and full-stroke clearance verified. [igusCF9 pp1–2](https://www.igus.com/us/pdf/cf9.pdf). Gland individual drawing specifies3–6.5mm, narrower than the family table's3–7mm; use the individual limit. M12 sealing-nut guidance0.8–1.5Nm, locknut1–2Nm. [Gland drawing](https://www.hammfg.com/files/parts/pdf/1427NCGM12B.pdf), [manufacturer table](https://www.hammfg.com/electronics/small-case/accessories/1427ncg). Do not grip multiple separate wires in one gland. Fixed cassette-end jacket clamps/guards are mechanical parts in the parent assembly.

The selected1mm² power cable replaces the earlier0.5mm² proposal and meets the SSR load-terminal minimum. Signal extensions use equal0.25mm² cores; all RTD pigtail solder transitions must be symmetrical and thermally isolated from high-current joints. Seven active conductors are required; never merge RTD return with heater return.

Wago221 fine-stranded minimum is0.14mm², larger than Omega26AWG≈0.129mm². Do not insert bare stock RTD leads directly into221. Extend via strain-relieved solder joints to suitable larger wire or a connector contact explicitly rated26AWG. [Wago221 wire range](https://www.wago.com/us/splicing-connectors-221), [carrier](https://www.wago.com/us/wire-splicing-connectors/mounting-carrier/p/221-500).
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

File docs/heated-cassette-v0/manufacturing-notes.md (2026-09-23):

# Manufacturing notes - LF-CAS-V0 Rev D

## Quote scope

One water-test prototype. Base quote: supply the aluminum parts and two guard sheets listed in manufacturing-bom.csv. Quote machining and Type II finishing separately. Foam, shim backing, guide tape, commercial hardware, electronics and assembly are owner-sourced; quote those only as separately labeled options. No pressure test, cosmetic color matching, cleanroom process, motor or rocker.

Quantities: one each roof, left side, right side, bezel, rear cover, drawer, front flange and nest; one left and one right rail; two risers; eight identical spacers; two identical guards; one moving and one fixed cable bracket; two identical jaws. The BOM groups identical pieces and points to one representative STEP each. Spacers may be cut and faced from plain aluminum tube: OD6, bore3.4, length8.00 +/-0.10; no anodize required. The optional-materials folder contains six tape profiles and a nominal shim reference, excluded from the base machining quote.

## Datums and anodizing

STEP uses assembly coordinates: X left/right, Y rearward, Z up. Housing closing-stop face is Y=0. All dimensions are FINISHED after coating. The shop compensates precoat sizes using its finishing process. Coating thickness is not equal to outward growth; confirm allowance with the finisher.
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

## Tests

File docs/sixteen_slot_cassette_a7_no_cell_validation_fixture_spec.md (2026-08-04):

# 16-Slot Cassette A7 No-Cell Validation Fixture Spec

Ticket: T-1C88E651

This A7 spec defines the no-cell validation fixture and bench acceptance plan for the first physical LaminarForge 16-slot AAV cassette build. It is subordinate to `docs/sixteen_slot_cassette_a0_interface_spec.md` and validates the A5 mechanical stack plus the A6 disposable fluid path before any cells, AAV, or sterile-use claims.

This is not a biological protocol, live-cell release criterion, sterile-barrier validation, AAV containment claim, or final vendor drawing. It specifies the controlled bench gate that must eventually prove the cassette can be assembled, sealed, primed, flowed, challenged with bubbles, drained, and measured repeatably using water, dye, or media-equivalent non-biological fluids.

Implementation status: the current Rust output is a dry layout/mockup package,
not an executable hydraulic validation fixture. Its surrogate chips and
restriction tokens are solid geometry, and it does not yet contain functional
flow passages, characterized resistance coupons, or the required dead-volume
dye station. Therefore it proves packaging and measurement-position intent
only. It cannot pass A7, unblock media-only planning, or support live-cell/AAV
claims.

The controlled operator procedure and blank execution forms are now defined in
`docs/sixteen_slot_cassette_no_cell_bench_validation_protocol.md` and
`docs/sixteen_slot_cassette_no_cell_bench_validation_data_sheets.md`. Their
release does not remove the functional-fixture, selected-hardware,
characterized-coupon, calibration, or frozen-stimulus blockers above.

## A7 Baseline

| Item | A7 requirement |
| --- | --- |
| First-build format | 16 slots in a 4 x 4 cassette. |
| Experimental unit | One cassette equals one AAV capsid/promoter/payload/dose/timing/media condition. |
| Validation material | DI water, dyed water, viscosity-adjusted surrogate, or media-equivalent non-biological fluid only. |
| Chip substitute | No-cell surrogate chips or restriction coupons matching the Rev C external footprint and inlet/outlet interface. |
| Flow path | A6 disposable one-condition single-pass harness. |
| Recirculation | Not validated by A7. Any recirculating future design needs its own validation ticket. |
| Mixed-AAV routing | Blocked. The fixture must not normalize using one cassette as a multi-AAV test article. |
| Incubation control | Out of scope except for dry fit, condensation/drain observation, and module keepout preservation. |
| Active mechanical contract | 699.04 x 541.92 x 24.00 mm carrier base body with 31.35 mm carrier true overall Z and 41.35 mm closed carrier/closure/lid stack; 151.76 x 109.48 mm slot pitch and 583.04 x 413.92 mm array. |
| Seal/closure contract | Sixteen independent, nonoverlapping per-slot lands, the perimeter land, and all hard stops top out at 7.35 mm and meet the lid underside; the 2.40 mm gasket compresses in 1.80 x 3.20 mm lid grooves. |

The active first-pass layout source for this fixture is `src/bin/sixteen_slot_cassette_no_cell_validation_fixture.rs`. It consumes the shared machine-readable A0 contract for cassette dimensions and exports the 4 x 4 cassette nest, solid surrogate/restriction layout set, pressure-sensor placement bar, flow-collection layout deck, bubble-station envelope, leak-witness tray, waste/backflow envelope, run-record plate, and review assembly under `output/no_cell_fixture/`. Local fixture dimensions may describe the surrounding bench deck, but they must not duplicate or override cassette geometry constants. Functional passages, sourced hardware, calibration, and characterized challenge articles remain blocked work.

The older `flow_pressure_validation_fixture`, `closed_chip_inlet_outlet_dead_volume_dye_recovery_station`, and related 20-position CAD generators are reference concepts only. They do not validate the 16-slot first article until explicitly ported to the 4 x 4 geometry, A5 datums, and A6 port map.

The shared machine-readable A0 contract supersedes the earlier overlapping seal-loop and unequal-height geometry. A7 fixtures use the corrected 24.00 x 24.00 mm inter-chip gutter, 6.00 mm inter-land clearance, common 7.35 mm seal-land/stop elevation, and 651.04 x 481.92 mm outer / 639.04 x 469.92 mm inner leak gutter rather than reproducing the defective predecessor geometry. The gutter is 6.00 mm wide x 3.00 mm deep with a 5.00 mm separating web; its 8.00 mm drain is centered at (315.52, -254.96, 10.00) mm and runs 40.00 mm along Y. The fixture must also preserve the nine 4.00 mm-diameter inter-slot stops, the 4.00 mm-wide perimeter web stops, the outside-gutter fasteners at X = +/-332.52 mm or Y = +/-247.96 mm, their 3.30 mm carrier pilots, and the 7.00 mm service relief below closure.

## Validation Questions

A7 answers these questions before the cassette is allowed into media-only or live-cell planning:

1. Can the A5 carrier/lid/gasket stack be assembled to the A3 compression target without damaging chips, blocking imaging windows, or losing datum registration?
2. Can the A6 harness be connected according to the port map without ambiguous routing, wrong-condition assembly, or unrestrained tubing movement?
3. Can all 16 no-cell surrogate paths prime without visible bubbles at the chip inlet witnesses?
4. Are row and slot flow rates balanced enough for one-condition AAV exposure screening?
5. Does pressure decay, visible dye inspection, and leak-tray capture show the stack is sealed at the selected test pressure?
6. Can the system detect known restriction, bypass, occlusion, bubble, waste backflow, and dead-volume failure modes?
7. Does repeated assembly remain within the same acceptance limits at the defined cycle checkpoints?

Failing any of these questions blocks live cells and AAV. Do not work around a failed bench gate with operator judgment.

## Fixture Architecture

The A7 fixture is a bench validation deck that holds the real A5 mechanical stack, the A6 disposable harness, and a controlled set of no-cell surrogate chips. It should be physically separate from the biological workflow until the sterile/aseptic path is validated.

Required fixture modules:

| Module | Function | Requirement |
| --- | --- | --- |
| Cassette nest | Locates the A5 carrier/lid/gasket stack | Seats the carrier bottom directly on datum A; contacts nominal rear, left, and front carrier edges with the rear/left rail inner faces and front lip; checks the D1 round and D2 relieved functional locators without loading D3/D4; preserves drain visibility; and exposes labels outside the gutter. |
| Surrogate-chip set | Replaces live chips for hydraulic tests | Sixteen footprint-matched coupons with known restriction and visible inlet/outlet witness regions. |
| External fault-insertion manifold and coupon set | Exercises pressure/flow detection without disturbing closure | Nominal, low-resistance, high-resistance, blocked, and bypass coupons must be independently characterized and selectable at frozen reference nodes without opening/retorquing the cassette, disturbing the harness/source condition, or revealing the blinded key. |
| Pressure sensor bar | Measures system and branch pressure | At minimum: common upstream, four row branches, waste/backpressure point, and optional selected slot outlets. |
| Flow collection deck | Captures slot or row outlet volumes | Sixteen labeled vial nests or gravimetric collection positions aligned to S01-S16. |
| Bubble challenge station | Introduces known bubbles upstream and by row | Includes a visible challenge inlet and a controlled path to W1/W3 waste during prime/debubble mode. |
| Leak witness tray | Detects visible dyed leaks | Wicking paper, clear leak moat, or dye-visible tray under gasket, connector, and waste handoff regions. |
| Waste/backflow station | Challenges siphon, overflow, and reverse pressure | Allows waste container high/low head tests without exposing the bench or cassette. |
| Dye/hold-up station | Measures tracer recovery and physical fluid hold-up | Includes quantitative dye injection/recovery, mutually exclusive fraction collection, and an independent volumetric hold-up ledger. |
| Run-record plate | Links physical setup to data | Shows cassette ID, harness ID, condition ID, slot map revision, operator, date/time, and pass/fail state. |

The fixture should make the wrong assembly obvious. Ports, rows, slots, and collection nests must use the same S01-S16 and G/M/W naming as A0/A6.

## Port And Measurement Map

A7 uses the A6 logical port assignments without freezing final connector SKUs.

| A6 port | A7 use |
| --- | --- |
| G0 | Reservoir/bag vent or controlled vent during no-cell pressure checks. |
| G1 | Regulated pressure input when pressure-driven tests are used. |
| G2 | Relief/exhaust or pressure-test vent to safe capture. |
| G3 | Reserved; cap unless a module-specific test needs it. |
| M0 | Main condition/surrogate feed inlet. |
| M1 | Rinse or media-equivalent feed inlet. |
| M2 | Prime/debubble bypass inlet. |
| M3 | Pressure/leak-test and dye-test inlet. |
| M4 | Sample/QC loop inlet if installed. |
| M5 | Inline sensor/cartridge service inlet if installed. |
| M6 | Spare; cap during first A7 testing. |
| W0 | Main chip outlet waste. |
| W1 | Prime/debubble purge waste. |
| W2 | Sample/QC waste if installed. |
| W3 | Leak-test/dye-test waste. |
| W4 | Relief/overflow/emergency waste. |

Minimum measurement points:

- Common upstream pressure before the branch split.
- Row branch pressure for R1, R2, R3, and R4.
- Waste/backpressure measurement near W0/W3.
- Sixteen collected outlet volumes or masses for S01-S16.
- Prime volume and time to bubble-clear state.
- Dye input, mutually exclusive recovered fractions, signed mass bias, tracer-equivalent unresolved loss, and separate physical hold-up upper bound.
- Leak-tray wet/dry or dye-visible result for the cassette, bulkhead, and waste handoff.

Preferred optional measurements:

- Inline flow sensor before the branch split.
- Row-level or selected-slot inline flow sensors.
- Upstream and downstream bubble-event sensor, if available.
- Temperature of the fluid and bench during long pressure/flow runs.
- Photographic record of gasket witness, bubble windows, leak tray, collection deck, and final dye state.

## No-Cell Test Sequence

Run the sequence in order. A later pass does not override an earlier failure unless the root cause is corrected and the affected test is repeated.

### 1. Incoming Inspection

- Confirm cassette revision, carrier/lid/gasket revision, harness revision, surrogate-chip set revision, and fixture revision.
- Confirm all sixteen surrogate chips fit their pockets without forcing.
- Confirm slot labels, row labels, G/M/W port labels, and collection positions match the run record.
- Confirm the global 96.00 x 12.00 mm barcode land and 118.00 x 10.00 mm text
  land remain at Y = -263.96 mm outside the leak gutter and clear of the front
  receiver row; confirm the bulkhead sensor/backplane cut remains centered at
  X = 320.00 mm without conflicting with W4.
- Confirm the 16 fastener centers clear the gutter, all 16 carrier receiver
  placeholders measure 3.30 mm before final threading/inserts, and the nine
  internal plus perimeter hard stops do not intersect a seal.
- Confirm unused ports are capped and documented.

Acceptance:

- 16/16 surrogate chips seat without interference.
- No visible chip-pocket obstruction, datum damage, gasket tear, clogged port, or mislabel.
- Any untracked harness or surrogate lot fails the run.

### 2. Dry Assembly And Compression Witness

- Assemble carrier, gasket, surrogate chips, lid/clamp, and fasteners using the A2/A3 torque sequence.
- Verify alignment through datum bosses and lid openings.
- Check gasket witness points and hard stops.
- Confirm imaging windows remain unobstructed.

Acceptance:

- Gasket witness height is within the A3 20-30% compression guard band, with the nominal target at 25%.
- If measured directly from the 2.40 mm nominal gasket assumption, compressed height should be 1.68-1.92 mm.
- The 7.35 mm per-slot lands, perimeter land, and hard stops contact the lid
  underside on one closure plane matching nominal chip protrusion. The nominal
  1.80 mm compressed gasket height is contained by the lid groove cavity; it is
  not a gap above a shorter land.
- No window, port, label, drain, or witness path is blocked by clamp hardware or tubing.

### 3. Harness Topology Check

- Connect the A6 disposable harness to the fixture without fluid.
- Trace reservoir, pump/pressure interface, prime bypass, four row feeds, sixteen slot inlets, sixteen slot outlets, row waste branches, and common waste.
- Scan or record cassette ID, harness ID, condition ID, slot map revision, and port map revision.

Acceptance:

- Every pigtail maps to the correct S01-S16 position.
- No tube crosses imaging openings, gasket lands, lid grooves, either hard-stop
  family, datum features, or drain inspection regions.
- Wrong-port ambiguity is grounds for fixture redesign, not operator training alone.

### 4. Prime-To-Waste Validation

- Fill the upstream path with water or dye-compatible surrogate fluid.
- Prime M0/M2 to W1 until the common upstream line, bubble window, and prime bypass are bubble-free.
- Prime row branches one row at a time.
- Prime each slot through the surrogate chip and collect outlet fluid.

Acceptance:

- 16/16 slot paths prime.
- No visible bubbles remain at common upstream, row high points, chip inlet witnesses, or outlet witnesses.
- Prime volume, time, pressure, and recovered waste are recorded.
- Any persistent bubble that requires manual tapping or tube manipulation is a design issue to log.

### 5. Bubble Challenge

- Introduce a calibrated upstream bubble or air slug using the bubble challenge station. Freeze its volume, injection uncertainty, location, flow condition, and photographic/optical evidence method in the approved run record before testing; an unset stimulus is an automatic gate failure.
- Run prime/debubble mode to W1/W3.
- Repeat by row if the harness has row-level high points.
- Observe chip inlet witnesses and outlet/bubble sensors if installed.

Acceptance:

- The introduced bubble clears to the prime/debubble waste path.
- No bubble reaches a chip inlet witness during the validated prime/debubble mode.
- No new trapped bubble remains at a row branch high point after the preapproved maximum clearing volume and time. An unset clearing limit is an automatic gate failure.
- The clearing volume and time are recorded for the volume ledger.

### 6. Pressure Decay And Visible Leak Test

- Fill the isolated loop with dyed liquid or the selected leak-test fluid.
- Stabilize the fixture for thermal and compliance effects.
- Pressurize to the selected no-cell leak-test pressure.
- After source isolation, acquire at least 661 seconds while inspecting
  leak-witness regions. Use the protocol-defined mean differential-pressure
  windows at t = 0-60 seconds and t = 600-660 seconds; their centers are exactly
  10 minutes apart.

Acceptance:

- No visible dyed leak at chip interfaces, gasket perimeter, bulkhead, connector handoffs, waste handoff, or drain paths.
- Pressure decay calculated from the two protocol-defined window means is <=5%.
- The installed system is tested at 1.5x selected maximum operating pressure using liquid and below every installed component's qualified proof-pressure limit. A selected part that cannot support that pressure fails selection.
- A separate representative gasket coupon or isolated gasket loop passes A3's max(35 kPa gauge, 1.5x maximum operating pressure) qualification gate.
- Routine planned operation must remain <=50% of the lowest credible temperature-derated failure/burst/connector limit after approved engineering margin and must not exceed a supplier-rated working pressure. The 1.5x installed proof checkpoint and a lone coupon result are margin evidence, not operating ratings.

If the fixture uses a known artificial leak to verify the detection method, that leak coupon must be physically isolated from release testing and clearly marked as a detector-verification tool.

### 7. Flow Balance Test

- Run the selected pump or pressure-control mode through all sixteen nominal surrogate chips.
- Collect outlet fluid from each slot for a fixed interval or target input volume while independently measuring actual input with a traceable source balance, calibrated displacement, or reference-flow method.
- Weigh or measure each S01-S16 collection position with matched evaporation blanks.
- Repeat after the system reaches pressure and compliance steady state.

Acceptance:

- Row collected-volume coefficient of variation is <=10%.
- Slot collected-volume coefficient of variation is <=10% for the characterized nominal no-cell surrogate set. Actual-chip limits require a separate evidence-backed gate.
- Every lane, row, mean, total, and collected-versus-measured-input recovery result remains in its frozen delivery band after uncertainty; CV alone cannot pass a uniformly starved system.
- Pressure drift is within +/-5% after stabilization for positive references; near-zero/negative gauge channels use a frozen absolute-kPa rule.
- Any systematic row or corner bias must pass the frozen spatial test or remain on HOLD for design review.

Gravimetric collection is the preferred early measurement because low-flow sensors can have substantial uncertainty at microfluidic flow rates.

### 8. Restriction, Occlusion, And Bypass Challenge

- Use a hydraulically equivalent, externally accessible fault-insertion manifold to select known low-resistance, high-resistance, blocked, and bypass challenges at the frozen nodes without replacing an in-pocket surrogate or disturbing the closure/harness/source condition. The current in-pocket solid layout tokens do not satisfy this requirement.
- Characterize each functional coupon independently before the cassette challenge. Freeze a finite resistance band and uncertainty for flowing coupons; for blocked coupons, freeze a one-sided maximum-flow/resistance lower bound and pressure signature because R = delta P / Q is not finite below LOQ. The current solid layout tokens do not satisfy this prerequisite.
- Run the pressure/flow profile used for nominal testing.
- Confirm the pressure sensor bar and collection deck detect the expected ordering.

Acceptance:

- Each flowing coupon remains within its preapproved finite resistance band; each blocked coupon satisfies its one-sided flow/resistance and pressure-signature limits.
- Blocked, bypass/low-resistance, high-resistance, and nominal signatures are separated by at least three combined standard uncertainties at the selected flow condition.
- The fixture identifies the affected row/slot without relying on visual inspection alone.

### 9. Dye-Recovery And Physical Hold-Up Test

- Inject a known dye volume through M3 or the selected dye-test inlet.
- Flush using the A6 planned prime/rinse path.
- Collect mutually exclusive S01-S16, W0/W3, rinse, leak/drain, and residual fractions so no fluid is counted twice.
- Compare corrected tracer mass recovery against input and use a separate volumetric inlet/output/rinse/residual ledger for physical hold-up.

Acceptance:

- Corrected tracer mass reconciles within +/-10% for first article.
- The one-sided upper bound on physical retained/hold-up volume remains below one chip dose or 10% of the formulated cassette condition volume, whichever is more conservative. Tracer non-closure alone is not labeled hydraulic dead volume. This gate cannot be waived.
- Dye above the validated location-specific detection threshold in connectors, filters, bubble elements, dead legs, gasket interfaces, or dry structure blocks expensive vector work until the loss is understood.

### 10. Waste Backflow, Siphon, And Overflow Challenge

- Run normal flow into the selected sealed waste bag or bottle.
- Challenge waste placement below and above cassette height within the planned bench/module envelope.
- Apply the preapproved high/low waste elevations and reverse head/backpressure using the waste/backflow station. The run record must state exact elevations, pressure, dwell, uncertainty, and secondary-containment capacity; unset challenge values are an automatic gate failure.
- Trigger the overflow/relief path if W4 is installed.

Acceptance:

- No waste backflow reaches chip outlets or row branches.
- No siphon drains the cassette outside commanded flow.
- Relief/overflow routes to secondary containment without wetting dry cassette structures.
- Waste identity and condition ID remain linked to the cassette run.

### 11. Repeat Assembly And Reconnection Cycling

- Repeat dry assembly, prime, leak, and flow checks at cycles 1, 5, 10, and 25.
- Include connector reconnection cycles when the selected bought connector or tube-welding workflow allows repeat handling.
- Record gasket, fastener, connector, surrogate-chip, and harness changes.

Acceptance:

- Cycle checkpoints meet the same prime, leak, and flow targets as cycle 1.
- Any loss of compression witness, cracked surrogate, thread damage, stripped insert, connector loosening, or route-label degradation blocks the affected design revision.

## Acceptance Gate Summary

The first-article cassette can move from A7 into media-only planning only when all required gates pass:

| Gate | Minimum pass condition |
| --- | --- |
| Fit and datum | 16/16 surrogate chips seat; cassette registers to rear/left datums; lid aligns without forcing. |
| Compression | A3 witness target met, nominally 20-30% squeeze with 25% target. |
| Harness map | Every port, row, slot, and waste path traceable to the run record. |
| Prime | 16/16 paths prime with no visible bubble at chip inlet witnesses. |
| Bubble challenge | Calibrated, preapproved bubble stimulus clears to W1/W3 within the frozen clearing volume/time without reaching chip inlet witnesses; unset stimulus/limits fail. |
| Leak | Installed system has no visible dye leak and guard-banded decay `100 x (P0 - P10) / P0 <= 5%` at 1.5x maximum operating pressure, using no active makeup, at least 661 s acquisition, P0 mean over t = 0-60 s, and P10 mean over t = 600-660 s; representative isolated gasket loop also passes A3 qualification. |
| Flow balance | Row and slot CV are each <=10%; every lane/row/mean/total and measured-input recovery stays within frozen bands; pressure drift passes its relative or near-zero absolute rule. |
| Restriction detection | Independently characterized flowing coupons remain in finite bands, blocked coupons meet one-sided limits, and predictive signatures meet the frozen three-standard-uncertainty separation rule. |
| Recovery/hold-up | Tracer recovery reconciles within +/-10%; the separate physical hold-up upper bound is below the A6 target with no discretionary waiver. |
| Waste safety | No backflow, siphon, or uncontrolled overflow into cassette or bench. |
| Repeatability | Cycles 1, 5, 10, and 25 pass the same required gates. |

No single aggregate pass/fail score is allowed. Each gate must be recorded independently because different downstream fixes own different failures.
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

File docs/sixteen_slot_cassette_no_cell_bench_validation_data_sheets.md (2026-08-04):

# 16-Slot Cassette No-Cell Bench Validation Data Sheets

Form set: LF-CAS-A7-P001-F
Revision: A1
Protocol: docs/sixteen_slot_cassette_no_cell_bench_validation_protocol.md
Readiness checklist: LF-CAS-A7-RC001 revision A0,
docs/sixteen_slot_cassette_hp0_hp2_readiness_checklist.md
Ticket: T-D713D22E

## Use Instructions

Duplicate this versioned blank form set for each run. Do not enter execution
data in the repository template. Every executed page must show protocol revision, run ID,
cassette serial, operator initials, independent-review initials, and page
number. Electronic records must retain the native raw file, an immutable
export, and SHA-256 hash.

Permitted status values are PASS, FAIL, INVALID, HOLD, NOT READY, and
prospectively approved N/A. Blank required fields are NOT READY. Corrections
must preserve the original entry and show initials/date/reason; do not erase or
overwrite the original.

This repository file is a versioned engineering template, not a QMS by itself.
The executed copy becomes controlled only when its record owner, immutable
storage location, access control, and retention rule are entered on DS-00.

### Reusable executed-page header

Copy this header to the top of every executed or duplicated DS page. A missing
required header field makes that page NOT READY and prevents its evidence from
closing a gate.

| Header field | Entry |
| --- | --- |
| Protocol ID/revision | |
| Form-set revision | |
| Readiness checklist ID/revision | LF-CAS-A7-RC001 revision A0 |
| Run ID | |
| Cassette serial/revision | |
| Harness ID/revision, when applicable | |
| Sheet ID and copy/trial/cycle identifier | |
| Operator initials/date-time/time zone | |
| Independent-review initials/date-time/time zone | |
| Page number / total pages | |
| Executed-record owner and immutable location | |

---

## DS-00 — Run Cover And Claim

| Field | Entry |
| --- | --- |
| Protocol ID/revision | |
| Form-set revision | |
| Readiness checklist ID/revision | LF-CAS-A7-RC001 revision A0 |
| Ticket ID | |
| Run ID | |
| Claim level: FA-1 / DV-3 / manufacturing confirmation | |
| Source commit | |
| Released drawing-set ID/revision | |
| STEP manifest ID/SHA-256 | |
| Release-manifest ID/SHA-256 | |
| Software/firmware/calculation revision manifest | |
| Cassette serial/revision | |
| Carrier/lid/window/bulkhead/dock serials and revisions | |
| Fastener/receiver set IDs, revisions, lots | |
| Harness serial/revision/lot | |
| Multi-harness/checkpoint assignment manifest, if applicable | |
| Gasket source material/lot | |
| Installed gasket assembly ID/revision | |
| Nominal surrogate-set revision | |
| Fault-coupon-set revision | |
| Fixture revision | |
| Slot-map and port-map revisions | |
| Rev C chip lot and metrology-record ID | |
| Intended Rev C chip count / measured count | |
| Spare Rev C chip count / measured count | |
| Rev C chip-lot metrology disposition | |
| D7 worst-case stack record/revision/disposition | |
| One-condition ID | |
| Test-fluid batch ID | |
| Operator | |
| Independent reviewer | |
| Safety reviewer | |
| Start date/time/time zone | |
| End date/time/time zone | |
| E1 environmental extension in scope? | |
| E2 cleaning/carryover extension in scope? | |
| Final disposition | |
| Final-report artifact ID | |
| Executed-record owner/immutable storage/retention rule | |
| Repository-template/non-QMS status acknowledged | |

### Claim limitations acknowledged

| Limitation | Operator initials/date | Reviewer initials/date |
| --- | --- | --- |
| Sixteen lanes are not sixteen independent cassette articles. | | |
| Repeated trials are not independent hardware articles. | | |
| No sterility, aseptic, live-cell, AAV-containment, recirculation, or mixed-condition claim. | | |
| FA-1 applies only to the listed serialized configuration. | | |

### Harness sample accounting

“Full-core” means topology through waste for P1-P3. “Checkpoint-only” means the
identified subset required at checkpoints 5/10/25. Select exactly one row and
reconcile every harness to the DS-00 manifest.

| Claim/connector plan | Required full-core harnesses | Required checkpoint-only harnesses | Required total | Selected? | Actual IDs/manifest | Status |
| --- | ---: | ---: | ---: | --- | --- | --- |
| FA-1, reconnect-rated | 1 | 0 | 1 | | | |
| FA-1, single-use | 1 | 3 | 4 | | | |
| DV-3, reconnect-rated | 3 | 0 | 3 | | | |
| DV-3, single-use | 3 | 3 | 6 | | | |
| Manufacturing confirmation, reconnect-rated | 3 | 0 | 3 | | | |
| Manufacturing confirmation, single-use | 3 | 9 | 12 | | | |

---

## DS-01 — Frozen Parameters And Acceptance Inputs

No wet work may begin until every applicable required row is approved.

| Parameter | Symbol | Frozen value/unit | Allowed tolerance or uncertainty | Source/rating record | Approver/date |
| --- | --- | --- | --- | --- | --- |
| Maximum operating pressure | MOP | | | | |
| Decay basis: differential/gauge pressure above ambient only | Delta P | | | | |
| Absolute-sensor conversion: Delta P = Psystem,abs - Pambient,abs; synchronized ambient reference and covariance method | | | | | |
| Installed liquid proof pressure = 1.5 x MOP | Pproof | | | | |
| Installed proof target tolerance | | | | | |
| Installed-system maximum permitted peak | | | | | |
| Isolated gasket pressure = max(35 kPa gauge, 1.5 x MOP) | Pgasket | | | | |
| Coupon burst target = max(3 x Pgasket, 100 kPa gauge) | Pburst | | | | |
| Installed-system relief setpoint and tolerance | Prelief | | | | |
| Pressure-source hard cap | | | | | |
| Coupon burst-rig maximum/test ceiling | | | | | |
| Coupon burst-rig weakest validated rating/component | | | | | |
| Coupon burst-rig relief lower bound / upper bound / hard cap | | | | | |
| Coupon burst-rig overshoot limit and abort trigger | | | | | |
| Pressure abort triggers and safe-depressurization route | | | | | |
| Pressure-source isolation/valve state and no-active-makeup rule | | | | | |
| Weakest validated component limit and component ID | Plimit | | | | |
| Credible derated failure/burst/connector limit after margin used for MOP <= 50% check; not proof or one-coupon result | | | | | |
| Effective isolated test volume and determination method | Veff | | | | |
| Maximum residual/trapped gas and verification method | | | | | |
| Compliance characterization method/range/record | | | | | |
| Pressure-hold stabilization band/rule | | | | | |
| Maximum fluid/ambient temperature change during hold | Delta T max | | | | |
| Decay acquisition duration and endpoint windows | | 11 min minimum; P0 = t 0-60 s, P10 = t 600-660 s | | | |
| Sealed-blank maximum decay/control band | | | | | |
| Calibrated artificial-leak control ID and leak rate/conductance | | | | | |
| Artificial-leak expected response band/signature | | | | | |
| Minimum detectable unacceptable leak and visual detection threshold | | | | | |
| Perimeter low-head stimulus liquid, volume/U, fill points, orientation, dwell, tracer threshold, capture/migration/drain limits | | | | | |
| Pump/control mode and command profile | | | | | |
| Nominal flow or pressure command | | | | | |
| Ramp limit | | | | | |
| Hydraulic stabilization rule | | | | | |
| Collection duration or target input volume | | | | | |
| DAQ sample rate | | | | | |
| Pressure-decay endpoint-center separation | | 600 s | | | |
| Pressure-decay upper limit | | 5% | | | |
| Pressure-drift upper limit | | 5% | | | |
| Pressure-drift reference/normalization mode by channel | | | | | |
| Near-zero threshold and absolute drift band by channel | | | | | |
| Slot-flow CV upper limit | | 10% | | | |
| Row-flow CV upper limit | | 10% | | | |
| Net-mass and lane-flow quantification limits | | | | | |
| Expected total/mean/per-lane nominal flow bands | | | | | |
| Expected per-row nominal flow bands R1-R4 | | | | | |
| Input-versus-output flow-recovery band | | | | | |
| Traceable measured-input reference method/instrument | | | | | |
| Persistent position-bias decision rule | | | | | |
| External non-disturbing fault-insertion manifold ID/revision | | | | | |
| Fault-manifold hydraulic-equivalence method/reference nodes/U | | | | | |
| Fault-manifold 16-selection, no-open/no-retorque/no-demate/no-source-change qualification | | | | | |
| Prime maximum volume, maximum time, pressure band, and recovery band | | | | | |
| Bubble volume | Vbubble | | | | |
| Bubble reference pressure/temperature and delivered-volume correction | | | | | |
| Bubble injection locations | | Common, R1-R4 | | | |
| Bubble optical detection limit | | | | | |
| Bubble maximum clearing time | | | | | |
| Bubble maximum clearing volume | | | | | |
| Waste low elevation/head | | | | | |
| Waste nominal elevation/head | | | | | |
| Waste high elevation/head | | | | | |
| Reverse pressure/head | | | | | |
| Waste challenge dwell | | | | | |
| Siphon-volume detection limit | | | | | |
| W4 overflow/relief stimulus | | | | | |
| W4 captured-volume recovery band | | | | | |
| W4 escaped-volume one-sided upper limit | | | | | |
| Waste reverse-tracer baseline/decision limit | | | | | |
| Frozen maximum releasable liquid inventory | | | | | |
| Secondary-containment capacity | | | | | |
| Containment capacity / maximum inventory ratio | | At least 110% | | | |
| One-chip-dose volume | Vchip | | | | |
| Cassette condition volume | Vcondition | | | | |
| Physical hold-up limit = min(Vchip, 0.10 x Vcondition) | Vhold,max | | | | |
| Dye/tracer identity and concentration | | | | | |
| Quantitative dye method/instrument/version | | | | | |
| Dye calibration range | | | | | |
| Dye method LOD/LOQ | | | | | |
| Dye reporting/decision limit and nondetect upper-bound rule | | | | | |
| Dye analytical recovery limits | | | | | |
| Residual-estimation method | | | | | |
| Persistent-retention validated visual/analytical threshold | | | | | |
| Pre-injection system/carryover-blank map, recovery rule, residual limit, and one-sided upper-bound rule | | | | | |
| Post-dye tracer-clear map, method, decision limit, and upper-bound rule before waste | | | | | |
| Fluid recipe, density, viscosity, temperature | | | | | |
| Final torque and tolerance | | | | | |
| Receiver configuration | | | | | |
| Closure settling rule | | At least 10 min; witness delta no more than 0.02 mm over 5 min; fail if not stable by 30 min | | | |
| Witness map | | | | | |
| Connector reuse classification/rated cycles | | | | | |
| Predictive class-separation method: z = abs(mu_a - mu_b) / sqrt(u_a^2 + u_b^2 - 2 cov_ab), k = 1; include instrument, within-coupon, between-coupon/class, and drift dispersion | | z at least 3 | | | |
| Measurement-uncertainty budget/method record | | | | | |
| Standard-u versus expanded-U convention, coverage factor k/probability | | | | | |
| Covariance/correlation treatment | | | | | |
| Conformity decision-rule version/record | | | | | |
| E1 temperature/RH/duration/log interval | | | | | |
| E1 stabilization, spatial range, temporal fluctuation, overshoot, recovery, RH, evaporation, and condensation definitions/limits | | | | | |
| E2 tracer loading/dwell and cleaning recipe | | | | | |
| E2 direct/rinse method, analytical reporting/decision limit, and carryover limit | | | | | |
| Fluid/cleaner SDS, PPE, disposal, and materials-compatibility review record | | | | | |
| Hazardous/flammable E2 chemistry SOP and risk-assessment IDs, or prospectively approved N/A | | | | | |
| Raw-file location/naming/hash method | | | | | |
| Calculation workbook/script version | | | | | |

### Installed-component pressure-rating matrix

Duplicate rows until every installed pressure/wetted component and every source,
relief, isolation, vent, and sensor boundary item is listed. Eight blank rows are
not a sample cap.

| Component ID | Function | Manufacturer/part/lot | MOP rating | Proof rating | Burst rating | Temperature derating | Source document | PASS/FAIL |
| --- | --- | --- | ---: | ---: | ---: | --- | --- | --- |
| | | | | | | | | |
| | | | | | | | | |
| | | | | | | | | |
| | | | | | | | | |
| | | | | | | | | |
| | | | | | | | | |
| | | | | | | | | |
| | | | | | | | | |

HP-0 disposition: __________
Design authority/date: __________
Fluidics validation lead/date: __________
Metrology lead/date: __________
Safety reviewer/date: __________
Quality reviewer/date: __________
Records custodian/date: __________

---

## DS-02 — Equipment, Calibration, And Measurement Controls

Duplicate equipment rows as needed; every instrument or safety function used by
the run must have its own identity and disposition.

Execute DS-02 as four separately signed immutable snapshots:

- DS-02A1 records the exact downselection decision at HP0-15.
- DS-02A2 cites A1 and records final selected-equipment capability, rating,
  calibration plan, and uncertainty at HP0-15A.
- DS-02B cites A2 and records exact received serials, current certificates,
  as-found/as-left checks, and only the pre-SAF commissioning controls needed
  before SAF-E02.
- DS-02C cites B and SAF-E02 and records post-SAF bubble, dye, and evaporation
  method controls before HP-1 release.

Never append a later stage to, replace, or re-hash an earlier signed file. For
DS-02A1/A2, mark as-found/as-left and both commissioning-control sections
prospectively N/A with the stage basis. For DS-02B, mark the DS-02C control
section prospectively N/A; sealed-blank/artificial-leak results belong only in
DS-08. For DS-02C, copy the applicable exact equipment identities from B and
mark unrelated rows prospectively N/A. Any blank required field is NOT READY.

| Snapshot-control field | Entry |
| --- | --- |
| Stage: DS-02A1 downselection / DS-02A2 final capability / DS-02B pre-SAF commissioning / DS-02C post-SAF method controls | |
| Snapshot record ID/revision | |
| Configuration/P&ID/BOM identity | |
| Immediate predecessor DS-02 record ID/revision/SHA-256; required for A2/B/C | |
| SAF-E02 ID/revision/SHA-256; required only for DS-02C | |
| Executed snapshot immutable location | |
| Detached sidecar-manifest ID/location assigned before signing; sidecar records the final file hash after signing | |

| Equipment ID | Function | Manufacturer/model/serial | Range/capacity | Resolution | Standard u / expanded U / k / coverage or budget link | Certificate/due date | Software/firmware | As-found check | As-left check | Status |
| --- | --- | --- | --- | --- | --- | --- | --- | --- | --- | --- |
| | Pump/controller | | | | | | | | | |
| | Upstream pressure | | | | | | | | | |
| | R1 pressure | | | | | | | | | |
| | R2 pressure | | | | | | | | | |
| | R3 pressure | | | | | | | | | |
| | R4 pressure | | | | | | | | | |
| | Waste/backpressure | | | | | | | | | |
| | Pressure reference | | | | | | | | | |
| | DAQ/clock | | | | | | | | | |
| | Balance | | | | | | | | | |
| | Check weights | | | | | | | | | |
| | Covered collection-vessel/nest set | | | | | | | | | |
| | Evaporation-blank vessel set, minimum three | | | | | | | | | |
| | Traceable measured-input mass/volume/displacement reference | | | | | | | | | |
| | Fluid-preparation mass/volume tools | | | | | | | | | |
| | Fluid-density method/instrument | | | | | | | | | |
| | Fluid-viscosity method/instrument | | | | | | | | | |
| | Fluid temperature | | | | | | | | | |
| | Ambient temperature | | | | | | | | | |
| | Bubble injector | | | | | | | | | |
| | Dye instrument | | | | | | | | | |
| | Torque driver | | | | | | | | | |
| | Dimensional instrument 1 | | | | | | | | | |
| | Dimensional instrument 2 | | | | | | | | | |
| | Waste elevation/head | | | | | | | | | |
| | Camera/bubble evidence | | | | | | | | | |
| | Installed-system relief device | | | | | | | | | |
| | Pressure-source hard-limit/interlock | | | | | | | | | |
| | Source-isolation/no-makeup valve | | | | | | | | | |
| | Safe vent/drain | | | | | | | | | |
| | Emergency stop | | | | | | | | | |
| | Secondary containment | | | | | | | | | |
| | Coupon burst rig/weakest pressure boundary | | | | | | | | | |
| | Coupon burst shield | | | | | | | | | |
| | Spill kit/electrical-separation control | | | | | | | | | |
| | E1 chamber reference/RH system, if applicable | | | | | | | | | |
| | E1 sixteen-probe slot-plane set, if applicable | | | | | | | | | |
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

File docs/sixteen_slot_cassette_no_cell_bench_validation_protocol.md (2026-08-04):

# 16-Slot Cassette No-Cell Bench Validation Protocol

Protocol ID: LF-CAS-A7-P001
Revision: A1
Ticket: T-D713D22E
Digital baseline: fbb0006e9f5ad4fd02b2b0aecd88e4c043c54f6e
Companion forms: docs/sixteen_slot_cassette_no_cell_bench_validation_data_sheets.md
Readiness checklist: LF-CAS-A7-RC001 revision A0,
docs/sixteen_slot_cassette_hp0_hp2_readiness_checklist.md

## Document Status
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

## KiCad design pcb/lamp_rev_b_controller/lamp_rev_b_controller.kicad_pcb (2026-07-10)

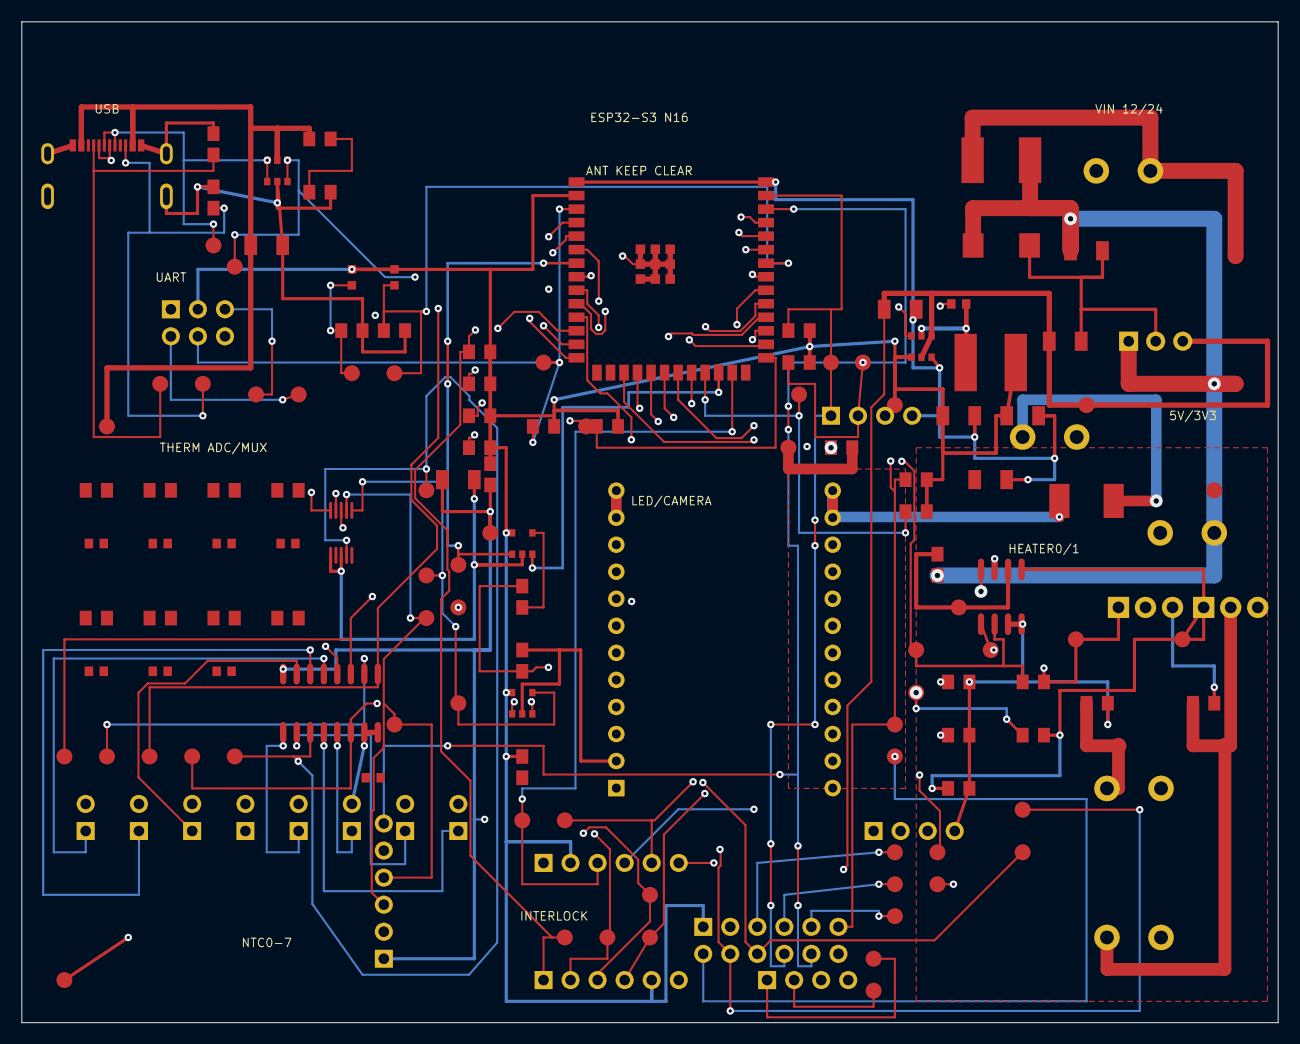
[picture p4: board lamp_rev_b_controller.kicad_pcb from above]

Board: 4 copper layers, 118.0 x 94.0 mm, 153 parts (0 on the bottom side), 72 nets.

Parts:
C1, C5, C6: 22uF rail bulk; C1206
C2: 22uF >=10V +5V buck output; C1206
C3: 22uF AP63203 input; C1206
C4: 22uF 50V VIN buck input; C1206
C7, C8: 22uF AP63203 output; C1206
C9: 100nF bootstrap; C0603
C10, C11, C12, C13, C14, C15, C16, C17: 100nF; C0603
D1: SMBJ18A footprint option; SMB_L4.6-W3.6-LS5.3-RD
D2, D3: LED0603 status; LED0603-RD
F1: RUEF500K/PTC; FUSE2920
FB1: 0805 ferrite bead / approved analog rail link fro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; R0805
J1: TYPE-C 3.1 MT 16P; USB-C-SMD_TYPE-C-USB-4
J2, J12, J13, J15: DB128H-5.08-2P-BK-S; TERM-BLOCK-5.08-2P
J4, J5, J6, J7, J8, J9, J10, J11: 2-pin NTC header; PINHEADER_1X02_2.54MM
J16: LED NTC/ID header; PINHEADER_1X04_2.54MM
J17: External camera sync header; PINHEADER_1X06_2.54MM
J18: SPI/FIFO camera module header; PINHEADER_2X06_2.54MM
J19: Lid/cartridge/cutoff interlock header; PINHEADER_1X06_2.54MM
J20: Fan PWM/tach header; PINHEADER_1X04_2.54MM
J21: 2x3 UART/programming header; PINHEADER_2X03_2.54MM
J22: I2C expansion header; PINHEADER_1X04_2.54MM
J23: Analog optical diagnostic header; PINHEADER_1X06_2.54MM
J24: DB128H-5.08-2P high-current heater cutoff loop/li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; TERM-BLOCK-5.08-2P
L1: Wurth 74439346068 6.8uH shielded inductor; IND_74439346068
Q1, Q2: IRLB3813PBF TO-220 12V prototype; TO-220-3_VERTICAL
R1, R2: 5.1k; R0805
R3, R4: 100k/100k VBUS sense; R0805
R10, R11, R12, R13, R14, R15, R16, R17: 10k 0.1%; R0805
R20, R21: 33R; R0805
R22, R23, R24, R48, R49: 10k; R0805
R25, R26: 50mR DNP option; R0805
R30, R31: 1k; R0805
R40, R41, R42, R43, R44, R45, R46, R47: 4.7k; R0805
R50: 100R LED DIM series; R0805
R51: 100k LED DIM pulldown; R0805
R52: 0R LED_SUPPLY feed link from VIN_PROTECTED; R0805
R53: 0.1R 1% >=1W LED current shunt; R2512
R54: 10k LED_FAULT_N pull-up; R0805
R55: 0R VDRV feed link from VIN_PROTECTED, 12 V popula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; R0805
TP_3V3: +3V3; TESTPOINT_SMD_1.5MM
TP_3V3A: +3V3_ANA; TESTPOINT_SMD_1.5MM
TP_5V: +5V; TESTPOINT_SMD_1.5MM
TP_ADS_AIN0: THERM_MUX_OUT; TESTPOINT_SMD_1.5MM
TP_ADS_AIN2: LED_CURRENT_SENSE; TESTPOINT_SMD_1.5MM
TP_ADS_AIN3: AUX_ANALOG_IN; TESTPOINT_SMD_1.5MM
TP_AUX_ANALOG: AUX_ANALOG_IN; TESTPOINT_SMD_1.5MM
TP_BOOT: ESP_GPIO0_BOOT; TESTPOINT_SMD_1.5MM
TP_CAM_CS: CAM_CS_N; TESTPOINT_SMD_1.5MM
TP_CAM_FRAME: CAM_FRAME_INT; TESTPOINT_SMD_1.5MM
TP_CAM_PWDN: CAM_PWDN_N; TESTPOINT_SMD_1.5MM
TP_CAM_RESET: CAM_RESET_N; TESTPOINT_SMD_1.5MM
TP_CART: CART_PRESENT_N; TESTPOINT_SMD_1.5MM
TP_CUTOFF: AUX_IO0_THERMAL_CUTOFF_OK; TESTPOINT_SMD_1.5MM
TP_EN: ESP_EN; TESTPOINT_SMD_1.5MM
TP_EXPOSURE: EXPOSURE_ACTIVE_IN; TESTPOINT_SMD_1.5MM
TP_FAN_PWM: FAN_PWM; TESTPOINT_SMD_1.5MM
TP_FAN_TACH: FAN_TACH; TESTPOINT_SMD_1.5MM
TP_FAULT: STATUS_FAULT_LED; TESTPOINT_SMD_1.5MM
TP_FRAME_TRIG: FRAME_TRIG_OUT; TESTPOINT_SMD_1.5MM
TP_GND: GND; TESTPOINT_SMD_1.5MM
TP_HEATER0_GATE: HEATER0_GATE; TESTPOINT_SMD_1.5MM
TP_HEATER0_LOW: HEATER0_LOW; TESTPOINT_SMD_1.5MM
TP_HEATER0_PWM: HEATER0_PWM; TESTPOINT_SMD_1.5MM
TP_HEATER1_GATE: HEATER1_GATE; TESTPOINT_SMD_1.5MM
TP_HEATER1_LOW: HEATER1_LOW; TESTPOINT_SMD_1.5MM
TP_HEATER1_PWM: HEATER1_PWM; TESTPOINT_SMD_1.5MM
TP_HEATER_ARM: HEATER_ARM; TESTPOINT_SMD_1.5MM
TP_I2C_SCL: I2C_SCL; TESTPOINT_SMD_1.5MM
TP_I2C_SDA: I2C_SDA; TESTPOINT_SMD_1.5MM
TP_LATCH: LATCH_LOCKED_N; TESTPOINT_SMD_1.5MM
TP_LED_EN: LED_EXC_EN; TESTPOINT_SMD_1.5MM
TP_LED_PWM: LED_EXC_PWM; TESTPOINT_SMD_1.5MM
TP_LED_SENSE: LED_CURRENT_SENSE; TESTPOINT_SMD_1.5MM
TP_LED_SUPPLY: LED_SUPPLY; TESTPOINT_SMD_1.5MM
TP_LED_SYNC: LED_SYNC_OUT; TESTPOINT_SMD_1.5MM
TP_LID: LID_CLOSED_N; TESTPOINT_SMD_1.5MM
TP_RUN: STATUS_RUN_LED; TESTPOINT_SMD_1.5MM
TP_SD_CS: SD_CS_N; TESTPOINT_SMD_1.5MM
TP_SPARE42: SPARE_GPIO42; TESTPOINT_SMD_1.5MM
TP_SPI_MISO: SPI_MISO; TESTPOINT_SMD_1.5MM
TP_SPI_MOSI: SPI_MOSI; TESTPOINT_SMD_1.5MM
TP_SPI_SCLK: SPI_SCLK; TESTPOINT_SMD_1.5MM
TP_THERM_EN: THERM_MUX_EN_N; TESTPOINT_SMD_1.5MM
TP_THERM_OUT: THERM_MUX_OUT; TESTPOINT_SMD_1.5MM
TP_THERM_S0: THERM_MUX_S0; TESTPOINT_SMD_1.5MM
TP_THERM_S1: THERM_MUX_S1; TESTPOINT_SMD_1.5MM
TP_THERM_S2: THERM_MUX_S2; TESTPOINT_SMD_1.5MM
TP_UART_RX: UART0_RXD; TESTPOINT_SMD_1.5MM
TP_UART_TX: UART0_TXD; TESTPOINT_SMD_1.5MM
TP_USB_CC1: USB_CC1; TESTPOINT_SMD_1.5MM
TP_USB_CC2: USB_CC2; TESTPOINT_SMD_1.5MM
TP_USB_DN: USB_DN; TESTPOINT_SMD_1.5MM
TP_USB_DP: USB_DP; TESTPOINT_SMD_1.5MM
TP_VBUS: VBUS; TESTPOINT_SMD_1.5MM
TP_VDRV: VDRV; TESTPOINT_SMD_1.5MM
TP_VIN: VIN_12_24; TESTPOINT_SMD_1.5MM
TP_VIN_HEATER: VIN_HEATER; TESTPOINT_SMD_1.5MM
TP_VIN_PROT: VIN_PROTECTED; TESTPOINT_SMD_1.5MM
U1: ESP32-S3-WROOM-1-N16; WIFIM-SMD_ESP32-S3-WROOM-1-N8
U2: USBLC6-2SC6; SOT-23-6
U3: Diodes AP63203WU-7 fixed 3.3V 2A buck; TSOT26_AP63203WU
U4: ADS1115IDGSR; MSOP-10_L3.0-W3.0-P0.50-LS5.0-BL
U5: CD74HC4051M; SOIC-16_L9.9-W3.9-P1.27-LS6.0-BL
U6: TC4427ACOA/TC4427EPA; SOIC-8_L4.9-W3.9-P1.27-LS6.0-BL
U7: CUI/Bel P7805-2000-S 5V 2A 8-36V buck module; han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; P78-2000-S_SIP3
U8: Mean Well LDD-700H 700mA CC buck LED driver; LDD-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; MEANWELL_LDD-300-1000H_THT
U9: SN74LVC1G08DBVR LED_EXC_PWM AND LED_EXC_EN; SOT-23-5
U10: INA180A1IDBVR gain 20 LED current sense; SOT-23-5

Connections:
3V3_BST: C9.1, U3.6
3V3_SW: C9.2, L1.1, U3.5
+3V3: C7.1, C8.1, D2.2, D3.2, FB1.1, J17.2, J18.1, J19.5, J21.2, J22.3, L1.2, R40.2, R41.2, R42.2, R43.2, R44.2, R45.2, R46.2, R47.2, R48.2, R49.2, R54.2, TP_3V3.1, U1.2, U3.1, U4.8, U9.5, U10.5
+3V3_ANA: C5.1, FB1.2, J16.3, J23.1, TP_3V3A.1, U5.16
+5V: C2.1, C3.1, J20.3, TP_5V.1, U3.2, U3.4, U7.3
AUX_ANALOG_IN: J16.2, J23.3, J23.4, TP_ADS_AIN3.1, TP_AUX_ANALOG.1, U4.7
AUX_IO0_THERMAL_CUTOFF_OK: J19.4, R47.1, TP_CUTOFF.1, U1.32
CAM_CS_N: J18.6, R42.1, TP_CAM_CS.1, U1.20
CAM_FRAME_INT: J18.7, TP_CAM_FRAME.1, U1.21
CAM_PWDN_N: J18.9, TP_CAM_PWDN.1, U1.22
CAM_RESET_N: J18.8, TP_CAM_RESET.1, U1.8
CART_PRESENT_N: J19.2, R45.1, TP_CART.1, U1.31
ESP_EN: J21.5, R48.1, TP_EN.1, U1.3
ESP_GPIO0_BOOT: J21.6, R49.1, TP_BOOT.1, U1.27
EXPOSURE_ACTIVE_IN: J17.4, TP_EXPOSURE.1, U1.29
FAN_PWM: J20.1, TP_FAN_PWM.1
FAN_TACH: J20.2, TP_FAN_TACH.1
FRAME_TRIG_OUT: J17.3, TP_FRAME_TRIG.1, U1.25
GND: C1.2, C2.2, C3.2, C4.2, C5.2, C6.2, C7.2, C8.2, D1.2, J1.13, J1.14, J1.15, J1.16, J1.A12B1, J1.B12A1, J2.2, J4.2, J5.2, J6.2, J7.2, J8.2, J9.2, J10.2, J11.2, J16.4, J17.1, J18.2, J18.12, J19.6, J20.4, J21.1, J22.4, J23.2, Q1.3, Q2.3, R1.2, R2.2, R4.2, R22.2, R23.2, R24.2, R25.2, R26.2, R30.2, R31.2, R51.2, TP_GND.1, U1.1, U1.40, U1.41, U2.2, U3.3, U4.1, U4.3, U5.7, U5.8, U6.3, U6.4, U7.2, U8.1, U8.2, U9.2, U10.2
HEATER0_GATE: Q1.1, R20.2, R23.1, TP_HEATER0_GATE.1, U6.7
HEATER0_LOW: J12.2, Q1.2, R25.1, TP_HEATER0_LOW.1
HEATER0_PWM: R20.1, TP_HEATER0_PWM.1, U1.10, U6.2
HEATER1_GATE: Q2.1, R21.2, R24.1, TP_HEATER1_GATE.1, U6.5
HEATER1_LOW: J13.2, Q2.2, R26.1, TP_HEATER1_LOW.1
HEATER1_PWM: R21.1, TP_HEATER1_PWM.1, U1.11, U6.8
HEATER_ARM: R22.1, TP_HEATER_ARM.1, U1.9, U6.1
I2C_SCL: J18.11, J22.2, J23.6, R41.1, TP_I2C_SCL.1, U1.38, U4.10
I2C_SDA: J18.10, J22.1, J23.5, R40.1, TP_I2C_SDA.1, U1.39, U4.9
LATCH_LOCKED_N: J19.3, R46.1, TP_LATCH.1
LED_CURRENT_SENSE: TP_ADS_AIN2.1, TP_LED_SENSE.1, U4.6, U10.4
LED_DIM_DRIVE: R50.2, R51.1, U8.22
LED_DIM_GATE: R50.1, U9.4
LED_DRV_PLUS: R53.1, U8.13, U8.14, U10.1
LED_EXC_EN: TP_LED_EN.1, U1.24, U9.3
LED_EXC_PWM: TP_LED_PWM.1, U1.7, U9.1
LED_MINUS: J15.2, U8.11, U8.12
LED_PLUS: J15.1, R53.2, U10.3
LED_SUPPLY: R52.2, TP_LED_SUPPLY.1, U8.23, U8.24
LED_SYNC_OUT: J17.5, TP_LED_SYNC.1, U1.28
LID_CLOSED_N: J19.1, R44.1, TP_LID.1, U1.30
SD_CS_N: R43.1, TP_SD_CS.1, U1.23
SPARE_GPIO42: J17.6, TP_SPARE42.1, U1.35
SPI_MISO: J18.5, TP_SPI_MISO.1, U1.19
SPI_MOSI: J18.4, TP_SPI_MOSI.1, U1.18
SPI_SCLK: J18.3, TP_SPI_SCLK.1, U1.17
STATUS_FAULT_LED: D3.1, R31.1, TP_FAULT.1, U1.34
STATUS_RUN_LED: D2.1, R30.1, TP_RUN.1, U1.33
THERM_CH_0: J4.1, U5.13
THERM_CH_1: J5.1, U5.14
THERM_CH_2: J6.1, U5.15
THERM_CH_3: J7.1, U5.12
THERM_CH_4: J8.1, U5.1
THERM_CH_5: J9.1, J16.1, U5.5
THERM_CH_6: J10.1, U5.2
THERM_CH_7: J11.1, U5.4
THERM_MUX_EN_N: TP_THERM_EN.1, U1.12, U5.6
THERM_MUX_OUT: TP_ADS_AIN0.1, TP_THERM_OUT.1, U4.4, U5.3
THERM_MUX_S0: TP_THERM_S0.1, U1.4, U5.11
THERM_MUX_S1: TP_THERM_S1.1, U1.5, U5.10
THERM_MUX_S2: TP_THERM_S2.1, U1.6, U5.9
UART0_RXD: J21.4, TP_UART_RX.1, U1.36
UART0_TXD: J21.3, TP_UART_TX.1, U1.37
USB_CC1: J1.A5, R1.1, TP_USB_CC1.1
USB_CC2: J1.B5, R2.1, TP_USB_CC2.1
USB_DN: J1.A7, J1.B7, TP_USB_DN.1, U1.13, U2.3, U2.4
USB_DP: J1.A6, J1.B6, TP_USB_DP.1, U1.14, U2.1, U2.6
USB_VBUS_SENSE: R3.2, R4.1
VBUS: C1.1, J1.A9B4, J1.B9A4, R3.1, TP_VBUS.1, U2.5
VDRV: R55.2, TP_VDRV.1, U6.6
VIN_12_24: F1.1, J2.1, TP_VIN.1
VIN_HEATER: C6.1, J12.1, J13.1, J24.2, TP_VIN_HEATER.1
VIN_PROTECTED: C4.1, D1.1, F1.2, J24.1, R52.1, R55.1, TP_VIN_PROT.1, U7.1

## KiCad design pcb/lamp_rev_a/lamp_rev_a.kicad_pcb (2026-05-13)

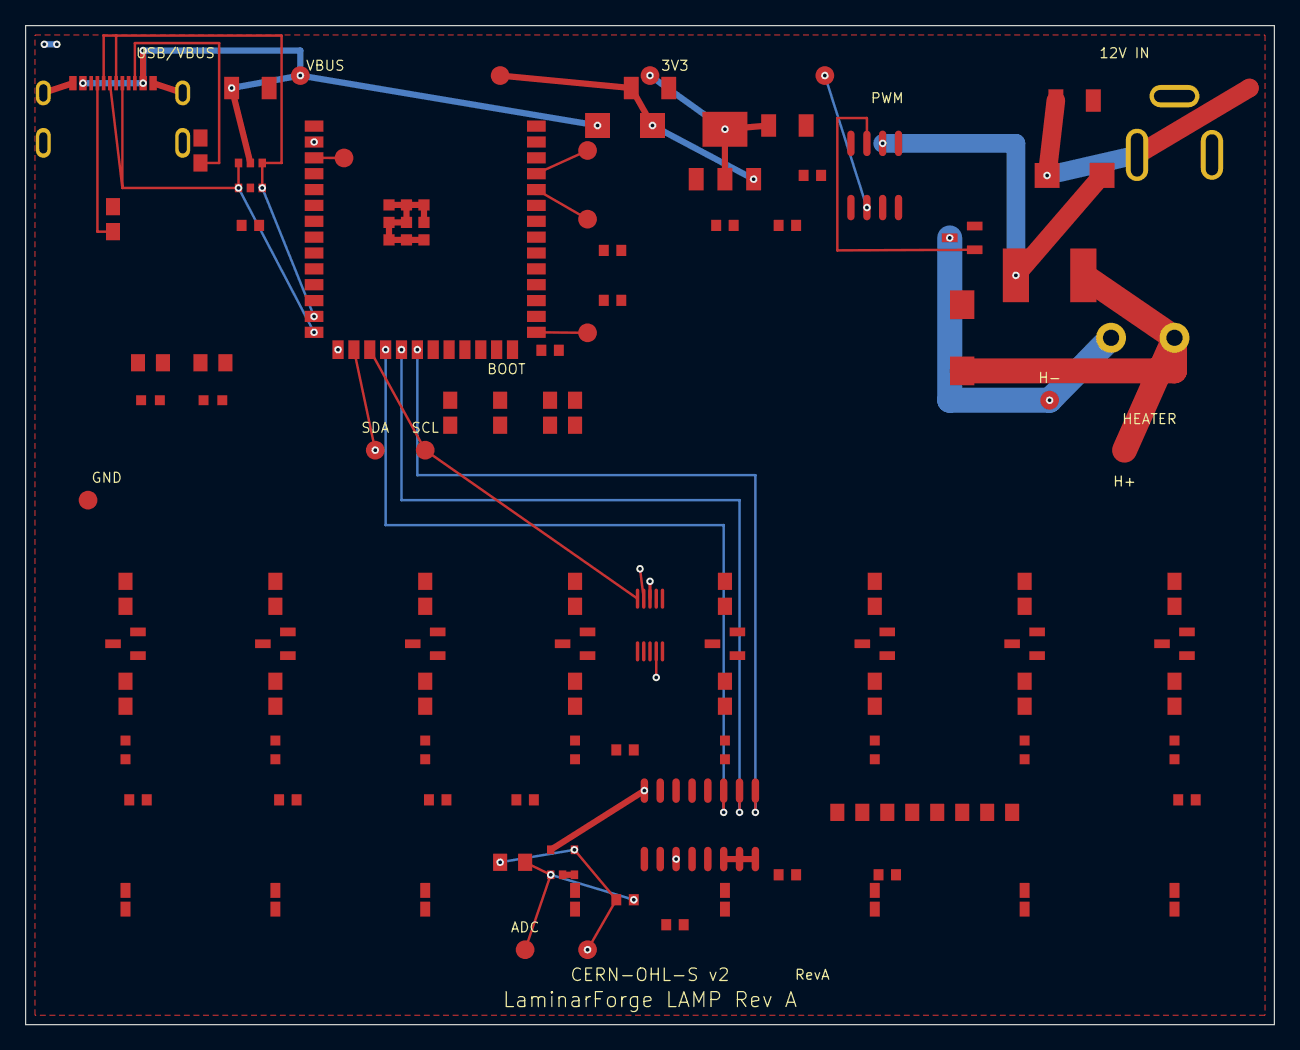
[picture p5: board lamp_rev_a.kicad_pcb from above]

Board: 4 copper layers, 100.0 x 80.0 mm, 107 parts (0 on the bottom side), 25 nets.

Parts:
C1, C2, C3, C4: 22uF; C1206
C5: 10pF; C0603
C6, C7, C8, C9, C10, C11, C12, C13, C14, C15, C16, C17, C18, C19, C20, C21: 100nF; C0603
D1, D13: SS34; SMA_L4.3-W2.6-LS5.2-RD
D2, D3, D4, D5, D6, D7, D8, D9, D11, D12: KT-0603R; LED0603-RD
D10: SMBJ18A; SMB_L4.6-W3.6-LS5.3-RD
F1: SMD2920-300C-36V; FUSE2920
J1: TYPE-C 3.1 MT 16P; USB-C-SMD_TYPE-C-USB-4
J2: DC-005-5A-2.0; DC-IN-TH_DC-005-5A-2.0
J3: DB128H-5.08-2P-BK-S; TERM-BLOCK-5.08-2P
PD1, PD2, PD3, PD4, PD5, PD6, PD7, PD8: SFH2704; PHOTODIODE-SMD-2X1.8
Q1: AO3400A; SOT-23-3_L2.9-W1.3-P1.90-LS2.4-BR
Q2, Q3, Q4, Q5, Q6, Q7, Q8, Q9: MMBT3904; SOT-23-3_L2.9-W1.3-P1.90-LS2.4-BR
R1, R2: 5.1k; R0805
R3: 1M; R0805
R4, R5, R6, R7, R8, R9, R10, R11: 100R; R0805
R12, R13, R14, R15, R16, R17, R18, R19, R20, R21: 1k; R0805
R22, R23: 4.7k; R0805
R24, R25, R26, R27, R28, R29: 10k; R0805
TP_3V3: +3V3; TESTPOINT_SMD_1.5MM
TP_5V: +5V; TESTPOINT_SMD_1.5MM
TP_12V: +12V_RAW; TESTPOINT_SMD_1.5MM
TP_ADC: ADC_AIN1; TESTPOINT_SMD_1.5MM
TP_BOOT: ESP_GPIO0; TESTPOINT_SMD_1.5MM
TP_EN: ESP_EN; TESTPOINT_SMD_1.5MM
TP_GND: GND; TESTPOINT_SMD_1.5MM
TP_HEATER: HEATER_P; TESTPOINT_SMD_1.5MM
TP_HEATER_SUPPLY: HEATER_SUPPLY; TESTPOINT_SMD_1.5MM
TP_MUX: MUX_COM; TESTPOINT_SMD_1.5MM
TP_PWM: HEATER_PWM; TESTPOINT_SMD_1.5MM
TP_RX: UART_RX; TESTPOINT_SMD_1.5MM
TP_SCL: SCL; TESTPOINT_SMD_1.5MM
TP_SDA: SDA; TESTPOINT_SMD_1.5MM
TP_TX: UART_TX; TESTPOINT_SMD_1.5MM
TP_VBUS: VBUS; TESTPOINT_SMD_1.5MM
U1: ESP32-S3-WROOM-1-N8; WIFIM-SMD_ESP32-S3-WROOM-1-N8
U2: USBLC6-2SC6; SOT-23-6
U3: AMS1117-3.3; SOT-223
U4: ADS1115IDGSR; MSOP-10_L3.0-W3.0-P0.50-LS5.0-BL
U5: CD74HC4051M; SOIC-16_L9.9-W3.9-P1.27-LS6.0-BL
U6: TLV6001IDBVR; SOT-23-5
U7: TC4427ACOA; SOIC-8_L4.9-W3.9-P1.27-LS6.0-BL

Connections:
+3V3: C3.1, TP_3V3.1, U1.2, U3.2, U3.4, U4.8, U5.16, U6.5
+5V: C2.1, D1.2, TP_5V.1, U3.3
+12V: D13.2, F1.1, U7.6
+12V_RAW: C4.1, D13.1, J2.1, TP_12V.1
ADC_AIN1: C5.2, R3.2, TP_ADC.1, U4.4, U6.1
ESP_EN: TP_EN.1, U1.3
ESP_GPIO0: TP_BOOT.1, U1.27
GATE_DRV: Q1.1, U7.7
GND: C1.2, C2.2, C3.2, C4.2, D10.2, J1.13, J1.14, J1.15, J1.16, J1.A12B1, J1.B12A1, J2.2, J2.3, Q1.2, R1.2, R2.2, TP_GND.1, U1.1, U1.41, U2.2, U3.1, U4.1, U4.3, U5.6, U5.7, U5.8, U6.2, U6.3, U7.3
HEATER_P: J3.2, Q1.3, TP_HEATER.1
HEATER_PWM: TP_PWM.1, U1.15, U7.2
HEATER_SUPPLY: D10.1, F1.2, J3.1, TP_HEATER_SUPPLY.1
MUX_COM: C5.1, R3.1, TP_MUX.1, U5.3, U6.4
MUX_S0: U1.18, U5.11
MUX_S1: U1.19, U5.10
MUX_S2: U1.20, U5.9
SCL: TP_SCL.1, U1.17, U4.10
SDA: TP_SDA.1, U1.16, U4.9
UART_RX: TP_RX.1, U1.36
UART_TX: TP_TX.1, U1.37
USB_CC1: J1.A5, R1.1
USB_CC2: J1.B5, R2.1
USB_DN: J1.A7, J1.B7, U1.13, U2.3, U2.4
USB_DP: J1.A6, J1.B6, U1.14, U2.1, U2.6
VBUS: C1.1, D1.1, J1.A9B4, J1.B9A4, TP_VBUS.1, U2.5

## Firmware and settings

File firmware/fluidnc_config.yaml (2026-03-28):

# =============================================================================
# FluidNC Configuration - LaminarForge Liquid Handler Robot
# =============================================================================
#
# 4-axis belt/leadscrew robot for automated liquid handling
#   X-axis: Belt-driven gantry (GT2 20T)
#   Y-axis: Belt-driven gantry (GT2 20T)
#   Z-axis: Belt-driven with 3:1 gear reduction (20T motor / 60T carriage)
#   I-axis: T8x2 lead screw syringe plunger (Hamilton 1710RN 100uL)
#
# MCU: ESP32-S3 DevKitC
# Drivers: 4x TMC2209 in UART mode (shared UART bus, individual addresses)
# PSU: 24V
#
# Steps/mm calculations (200 steps/rev, 16 microsteps = 3200 steps/rev):
#   X/Y: GT2 20T, pitch dia 12.73mm, circ = pi * 12.73 = 39.98mm
#         3200 / 39.98 = 80.04 steps/mm
#   Z:   Same pulley with 3:1 reduction -> 80.04 * 3 = 240.12 steps/mm
#   I:   T8x2 lead screw, 2mm lead -> 3200 / 2 = 1600 steps/mm
#
# Syringe volume calibration (Hamilton 1710RN 100uL, barrel ID 1.46mm):
#   Barrel area = pi * (0.73mm)^2 = 1.6742 mm^2
#   1 uL = 1 mm^3 -> 1 uL requires 1 / 1.6742 = 0.5973 mm travel
#   100 uL full stroke ~ 59.73 mm (mechanical travel limited to 30mm ~ 50.2 uL)
#
# =============================================================================

name: "LaminarForge Liquid Handler"
board: "ESP32-S3 DevKitC"

# ---------------------------------------------------------------------------
# Stepping engine
# ---------------------------------------------------------------------------
stepping:
  engine: RMT         # ESP32-S3 RMT peripheral for precise pulse generation
  idle_ms: 250        # ms before motors de-energize after idle
  pulse_us: 4         # step pulse width (microseconds)
  dir_delay_us: 1     # direction change settle time

# ---------------------------------------------------------------------------
# UART bus for TMC2209 drivers (shared single-wire UART)
# ---------------------------------------------------------------------------
uart1:
  txd_pin: gpio.17
  rxd_pin: gpio.18
  baud: 115200
  mode: 8N1

# ---------------------------------------------------------------------------
# Axes
# ---------------------------------------------------------------------------
axes:
  shared_stepper_disable_pin: NO_PIN   # each driver has its own enable

  # -------------------------------------------------------------------------
  # X-axis: Belt-driven gantry
  #   GT2 belt, 20-tooth pulley, pitch diameter 12.73mm
  #   80.04 steps/mm
  # -------------------------------------------------------------------------
  x:
    steps_per_mm: 80.040
    max_rate_mm_per_min: 6000.0      # 100 mm/s
    acceleration_mm_per_sec2: 500.0
    max_travel_mm: 300.0
    soft_limits: true
    homing:
      cycle: 1
      positive_direction: false       # home toward min
      mpos_mm: 0.0
      feed_mm_per_min: 600.0         # 10 mm/s homing seek
      seek_mm_per_min: 3000.0        # 50 mm/s fast seek
      settle_ms: 250
      seek_scaler: 1.100
      feed_scaler: 1.100

    motor0:
      limit_neg_pin: gpio.4
      limit_pos_pin: NO_PIN
      hard_limits: true
      pulloff_mm: 2.0
      tmc_2209:
        uart_num: 1
        addr: 0
        r_sense_ohms: 0.110
        run_current_amps: 0.800       # conservative for NEMA 17
        hold_current_amps: 0.400
        microsteps: 16
        stallguard: 40
        direction_pin: gpio.5
        step_pin: gpio.6
        disable_pin: gpio.7

  # -------------------------------------------------------------------------
  # Y-axis: Belt-driven gantry
  #   Identical drive to X-axis
  #   80.04 steps/mm
  # -------------------------------------------------------------------------
  y:
    steps_per_mm: 80.040
    max_rate_mm_per_min: 6000.0      # 100 mm/s
    acceleration_mm_per_sec2: 500.0
    max_travel_mm: 300.0
    soft_limits: true
    homing:
      cycle: 2
      positive_direction: false
      mpos_mm: 0.0
      feed_mm_per_min: 600.0
      seek_mm_per_min: 3000.0
      settle_ms: 250
      seek_scaler: 1.100
      feed_scaler: 1.100

    motor0:
      limit_neg_pin: gpio.15
      limit_pos_pin: NO_PIN
      hard_limits: true
      pulloff_mm: 2.0
      tmc_2209:
        uart_num: 1
        addr: 1
        r_sense_ohms: 0.110
        run_current_amps: 0.800
        hold_current_amps: 0.400
        microsteps: 16
        stallguard: 40
        direction_pin: gpio.16
        step_pin: gpio.8
        disable_pin: gpio.9

  # -------------------------------------------------------------------------
  # Z-axis: Belt-driven with 3:1 gear reduction
  #   20T motor pulley -> 60T carriage pulley
  #   240.12 steps/mm
  # -------------------------------------------------------------------------
  z:
    steps_per_mm: 240.120
    max_rate_mm_per_min: 3000.0      # 50 mm/s
    acceleration_mm_per_sec2: 200.0
    max_travel_mm: 100.0
    soft_limits: true
    homing:
      cycle: 3                        # home Z before I, after X/Y
      positive_direction: false       # home toward min (Z up / retracted)
      mpos_mm: 0.0
      feed_mm_per_min: 300.0         # 5 mm/s homing seek
      seek_mm_per_min: 1500.0        # 25 mm/s fast seek
      settle_ms: 500                  # extra settle to avoid bounce
      seek_scaler: 1.100
      feed_scaler: 1.100

    motor0:
      limit_neg_pin: gpio.10
      limit_pos_pin: NO_PIN
      hard_limits: true
      pulloff_mm: 1.0
      tmc_2209:
        uart_num: 1
        addr: 2
        r_sense_ohms: 0.110
        run_current_amps: 0.900       # slightly higher for geared axis
        hold_current_amps: 0.500
        microsteps: 16
        stallguard: 50
        direction_pin: gpio.11
        step_pin: gpio.12
        disable_pin: gpio.13

  # -------------------------------------------------------------------------
  # I-axis: Syringe plunger (Hamilton 1710RN 100uL)
  #   T8x2 lead screw: 2mm pitch, 2mm lead, 1 start
  #   1600 steps/mm
  #   Very gentle acceleration to avoid bubble formation / splashing
  #   Homes to plunger fully retracted (min position)
  # -------------------------------------------------------------------------
  i:
    steps_per_mm: 1600.000
    max_rate_mm_per_min: 300.0       # 5 mm/s
    acceleration_mm_per_sec2: 100.0   # gentle for liquid handling
    max_travel_mm: 30.0              # ~50.2 uL with Hamilton 1710RN
    soft_limits: true
    homing:
      cycle: 4                        # home last (after Z is safe)
      positive_direction: false       # home to plunger fully retracted
      mpos_mm: 0.0
      feed_mm_per_min: 60.0          # 1 mm/s - very slow for syringe
      seek_mm_per_min: 150.0         # 2.5 mm/s seek
      settle_ms: 1000                 # long settle for fluid stabilization
      seek_scaler: 1.100
      feed_scaler: 1.100

    motor0:
      limit_neg_pin: gpio.14
      limit_pos_pin: NO_PIN
      hard_limits: true
      pulloff_mm: 0.5                 # minimal pulloff for syringe
      tmc_2209:
        uart_num: 1
        addr: 3
        r_sense_ohms: 0.110
        run_current_amps: 0.600       # lower current, leadscrew is efficient
        hold_current_amps: 0.350
        microsteps: 16
        stallguard: 30                # lower threshold - leadscrew has more drag
        direction_pin: gpio.21
        step_pin: gpio.47
        disable_pin: gpio.48

# ---------------------------------------------------------------------------
# SPI / I2C (reserved, unused for now)
# ---------------------------------------------------------------------------
spi:
  miso_pin: NO_PIN
  mosi_pin: NO_PIN
  sck_pin: NO_PIN

i2c0:
  sda_pin: gpio.1
  scl_pin: gpio.2
  frequency: 100000

# ---------------------------------------------------------------------------
# Control pins
# ---------------------------------------------------------------------------
control:
  safety_door_pin: NO_PIN
  reset_pin: NO_PIN
  feed_hold_pin: NO_PIN
  cycle_start_pin: NO_PIN

# ---------------------------------------------------------------------------
# Probe pin (for tip-touch liquid level detection, future use)
# ---------------------------------------------------------------------------
probe:
  pin: gpio.38                        # ADC1 capable for analog sensing
  check_mode_start: true

# ---------------------------------------------------------------------------
# Coolant / auxiliary outputs (for valve control)
# ---------------------------------------------------------------------------
coolant:
  flood_pin: gpio.39                  # repurposed: solenoid valve 1
  mist_pin: gpio.40                   # repurposed: solenoid valve 2

# ---------------------------------------------------------------------------
# Status LED
# ---------------------------------------------------------------------------
user_outputs:
  analog0_pin: NO_PIN
  analog1_pin: NO_PIN
  digital0_pin: gpio.41               # status LED
  digital1_pin: gpio.42               # error LED
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

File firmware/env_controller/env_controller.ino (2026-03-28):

/*
 * env_controller.ino — Main firmware
 * LaminarForge Incubation Enclosure Environmental Controller
 * Target: ESP32-S3 DevKitC (#2, separate from FluidNC motion controller)
 *
 * Controls:
 *   - Enclosure temperature (PID, 2x DS18B20 + 2x silicone heater pads)
 *   - CO2 concentration (bang-bang, SprintIR-6S-5 + solenoid valve)
 *   - Humidity monitoring (BME280, read-only)
 *   - Rocker platform (MG996R servo, pause-aware)
 *   - Peltier reservoir temperature (warm 37C / cold 4C, on/off hysteresis)
 *
 * Libraries required:
 *   - OneWire
 *   - DallasTemperature
 *   - Adafruit_BME280
 *   - ESP32Servo
 */

#include <OneWire.h>
#include <DallasTemperature.h>
#include <Wire.h>
#include <Adafruit_BME280.h>
#include <ESP32Servo.h>

#include "config.h"
#include "pid.h"

// ===========================================================================
// Global Objects
// ===========================================================================

// DS18B20 temperature sensors (shared 1-Wire bus).
OneWire           oneWire(PIN_ONEWIRE);
DallasTemperature tempSensors(&oneWire);
DeviceAddress     sensorAddr[SENSOR_COUNT];

// BME280 humidity sensor.
Adafruit_BME280   bme;
bool              bmeAvailable = false;

// SprintIR CO2 sensor on HardwareSerial 1.
HardwareSerial    co2Serial(1);

// Rocker servo.
Servo             rockerServo;

// PID controller for enclosure temperature.
PIDController     tempPID(TEMP_PID_KP, TEMP_PID_KI, TEMP_PID_KD,
                          TEMP_PID_OUTPUT_MIN, TEMP_PID_OUTPUT_MAX,
                          TEMP_PID_INTEGRAL_MAX);

// ===========================================================================
// State Variables
// ===========================================================================

// Temperature.
float   tempSetpoint       = TEMP_SETPOINT_DEFAULT;
float   tempEnclosureA     = 0.0f;
float   tempEnclosureB     = 0.0f;
float   tempEnclosureAvg   = 0.0f;
float   heaterPwmValue     = 0.0f;
bool    thermalRunaway      = false;

// CO2.
float   co2Setpoint        = CO2_SETPOINT_DEFAULT;
int32_t co2Ppm             = 0;           // current reading in ppm
bool    co2SolenoidOpen    = false;
unsigned long co2LastReadMs = 0;

// CO2 hysteresis thresholds (derived from setpoint).
int32_t co2LowPpm         = CO2_LOW_THRESHOLD;
int32_t co2HighPpm        = CO2_HIGH_THRESHOLD;

// Humidity.
float   humidity           = 0.0f;
float   bmeTemp            = 0.0f;

// Peltier reservoirs.
float   tempWarm           = 0.0f;
float   tempCold           = 0.0f;
bool    peltierWarmOn      = false;
bool    peltierColdOn      = false;

// Rocker.
int     rockerAngle        = ROCKER_CENTER;
int     rockerTargetAngle  = ROCKER_ANGLE_MAX;
bool    rockerPaused       = false;
bool    rockerPhasePositive = true;       // true = at +10, false = at -10
unsigned long rockerPhaseStartMs = 0;
unsigned long rockerTransitionStartMs = 0;
int     rockerTransitionFrom = ROCKER_CENTER;
bool    rockerInTransition  = false;

// Timing.
unsigned long lastTempReadMs    = 0;
unsigned long lastCo2ReadMs     = 0;
unsigned long lastBmeReadMs     = 0;
unsigned long lastReportMs      = 0;
unsigned long lastPidMs         = 0;

// CO2 UART parsing buffer.
char    co2Buffer[32];
uint8_t co2BufIdx          = 0;

// ===========================================================================
// Forward Declarations
// ===========================================================================
void readTemperatures();
void runTemperaturePID();
void readCO2();
void runCO2Control();
void readHumidity();
void updateRocker();
void runPeltierControl();
void printStatusReport();
void processSerialCommand();
void setCO2Setpoint(float pct);
void setServoAngle(int angleDeg);
void emergencyHeaterShutdown();

// ===========================================================================
// Setup
// ===========================================================================
void setup() {
    Serial.begin(SERIAL_BAUD);
    delay(500);
    Serial.println("ENV_CTRL: LaminarForge Incubation Enclosure v1.0");
    Serial.println("ENV_CTRL: Initializing...");

    // -----------------------------------------------------------------------
    // Heater PWM setup (ESP32 LEDC).
    // -----------------------------------------------------------------------
    ledcSetup(HEATER_PWM_CH_A, HEATER_PWM_FREQ, HEATER_PWM_RES);
    ledcSetup(HEATER_PWM_CH_B, HEATER_PWM_FREQ, HEATER_PWM_RES);
    ledcAttachPin(PIN_HEATER_A, HEATER_PWM_CH_A);
    ledcAttachPin(PIN_HEATER_B, HEATER_PWM_CH_B);
    ledcWrite(HEATER_PWM_CH_A, 0);
    ledcWrite(HEATER_PWM_CH_B, 0);
    Serial.println("ENV_CTRL: Heater PWM initialized (25 kHz)");

    // -----------------------------------------------------------------------
    // DS18B20 temperature sensors.
    // -----------------------------------------------------------------------
    tempSensors.begin();
    int found = tempSensors.getDeviceCount();
    Serial.print("ENV_CTRL: Found ");
    Serial.print(found);
    Serial.println(" DS18B20 sensor(s) on 1-Wire bus");

    for (int i = 0; i < SENSOR_COUNT && i < found; i++) {
        if (tempSensors.getAddress(sensorAddr[i], i)) {
            tempSensors.setResolution(sensorAddr[i], 12);  // 12-bit = 0.0625C
            Serial.print("ENV_CTRL:   Sensor ");
            Serial.print(i);
            Serial.print(" addr: ");
            for (int j = 0; j < 8; j++) {
                if (sensorAddr[i][j] < 0x10) Serial.print("0");
                Serial.print(sensorAddr[i][j], HEX);
            }
            Serial.println();
        }
    }

    if (found < SENSOR_COUNT) {
        Serial.print("ENV_CTRL: WARNING - Expected ");
        Serial.print(SENSOR_COUNT);
        Serial.print(" sensors, found ");
        Serial.println(found);
    }

    // Request first reading (non-blocking mode).
    tempSensors.setWaitForConversion(false);
    tempSensors.requestTemperatures();

    // -----------------------------------------------------------------------
    // CO2 sensor UART.
    // -----------------------------------------------------------------------
    co2Serial.begin(CO2_UART_BAUD, SERIAL_8N1, PIN_CO2_RX, PIN_CO2_TX);
    co2LastReadMs = millis();
    Serial.println("ENV_CTRL: SprintIR CO2 UART initialized (9600 baud)");

    // -----------------------------------------------------------------------
    // CO2 solenoid valve (off by default).
    // -----------------------------------------------------------------------
    pinMode(PIN_CO2_SOLENOID, OUTPUT);
    digitalWrite(PIN_CO2_SOLENOID, LOW);
    Serial.println("ENV_CTRL: CO2 solenoid OFF");

    // -----------------------------------------------------------------------
    // BME280 humidity sensor.
    // -----------------------------------------------------------------------
    Wire.begin(PIN_I2C_SDA, PIN_I2C_SCL);
    if (bme.begin(BME280_I2C_ADDR, &Wire)) {
        bmeAvailable = true;
        // Configure for low-power weather monitoring mode.
        bme.setSampling(Adafruit_BME280::MODE_FORCED,
                        Adafruit_BME280::SAMPLING_X1,   // temperature
                        Adafruit_BME280::SAMPLING_NONE,  // pressure
                        Adafruit_BME280::SAMPLING_X1,   // humidity
                        Adafruit_BME280::FILTER_OFF);
        Serial.println("ENV_CTRL: BME280 initialized");
    } else {
        Serial.println("ENV_CTRL: WARNING - BME280 not found at 0x76");
    }

    // -----------------------------------------------------------------------
    // Rocker servo.
    // -----------------------------------------------------------------------
    ESP32PWM::allocateTimer(2);  // Use timer 2 (timers 0,1 used by heaters)
    rockerServo.setPeriodHertz(50);
    rockerServo.attach(PIN_SERVO, 500, 2500);  // MG996R typical range
    setServoAngle(ROCKER_CENTER);
    rockerPhaseStartMs = millis();
    Serial.println("ENV_CTRL: Rocker servo centered");

    // -----------------------------------------------------------------------
    // Pause input from motion controller.
    // -----------------------------------------------------------------------
    pinMode(PIN_PAUSE, INPUT_PULLDOWN);

    // -----------------------------------------------------------------------
    // Peltier H-bridge pins.
    // -----------------------------------------------------------------------
    // Warm reservoir: heating mode (IN1=HIGH, IN2=LOW).
    pinMode(PIN_PELTIER_WARM_EN, OUTPUT);
    pinMode(PIN_PELTIER_WARM_IN1, OUTPUT);
    pinMode(PIN_PELTIER_WARM_IN2, OUTPUT);
    digitalWrite(PIN_PELTIER_WARM_EN, LOW);
    digitalWrite(PIN_PELTIER_WARM_IN1, HIGH);
    digitalWrite(PIN_PELTIER_WARM_IN2, LOW);

    // Cold reservoir: cooling mode (IN1=LOW, IN2=HIGH).
    pinMode(PIN_PELTIER_COLD_EN, OUTPUT);
    pinMode(PIN_PELTIER_COLD_IN1, OUTPUT);
    pinMode(PIN_PELTIER_COLD_IN2, OUTPUT);
    digitalWrite(PIN_PELTIER_COLD_EN, LOW);
    digitalWrite(PIN_PELTIER_COLD_IN1, LOW);
    digitalWrite(PIN_PELTIER_COLD_IN2, HIGH);
    Serial.println("ENV_CTRL: Peltier H-bridges initialized");

    // -----------------------------------------------------------------------
    // Done.
    // -----------------------------------------------------------------------
    lastPidMs = millis();
    Serial.println("ENV_CTRL: Initialization complete");
    Serial.println();
}

// ===========================================================================
// Main Loop
// ===========================================================================
void loop() {
    unsigned long now = millis();

    // -- Temperature sensors (every 1s) ------------------------------------
    if (now - lastTempReadMs >= TEMP_READ_INTERVAL_MS) {
        readTemperatures();
        runTemperaturePID();
        runPeltierControl();
        lastTempReadMs = now;
    }

    // -- CO2 sensor (every 2s) ---------------------------------------------
    if (now - lastCo2ReadMs >= CO2_READ_INTERVAL_MS) {
        readCO2();
        runCO2Control();
        lastCo2ReadMs = now;
    }

    // -- Continuously parse incoming CO2 UART data -------------------------
    while (co2Serial.available()) {
        char c = co2Serial.read();
        if (c == '\n') {
            co2Buffer[co2BufIdx] = '\0';
            parseCO2Response();
            co2BufIdx = 0;
        } else if (c != '\r' && co2BufIdx < sizeof(co2Buffer) - 1) {
            co2Buffer[co2BufIdx++] = c;
        }
    }

    // -- BME280 humidity (every 5s) ----------------------------------------
    if (now - lastBmeReadMs >= BME_READ_INTERVAL_MS) {
        readHumidity();
        lastBmeReadMs = now;
    }

    // -- Rocker platform ---------------------------------------------------
    updateRocker();

    // -- Serial status report (every 5s) -----------------------------------
    if (now - lastReportMs >= REPORT_INTERVAL_MS) {
        printStatusReport();
        lastReportMs = now;
    }

    // -- Process incoming serial commands ----------------------------------
    if (Serial.available()) {
        processSerialCommand();
    }
}

// ===========================================================================
// Temperature
// ===========================================================================
void readTemperatures() {
    // Collect results from previous async request.
    tempEnclosureA = tempSensors.getTempC(sensorAddr[SENSOR_ENCLOSURE_A]);
    tempEnclosureB = tempSensors.getTempC(sensorAddr[SENSOR_ENCLOSURE_B]);
    tempWarm       = tempSensors.getTempC(sensorAddr[SENSOR_WARM_RESERVOIR]);
    tempCold       = tempSensors.getTempC(sensorAddr[SENSOR_COLD_RESERVOIR]);

    // Handle disconnected sensors (DallasTemperature returns -127).
    if (tempEnclosureA < -100.0f) tempEnclosureA = tempEnclosureB;
    if (tempEnclosureB < -100.0f) tempEnclosureB = tempEnclosureA;

    tempEnclosureAvg = (tempEnclosureA + tempEnclosureB) / 2.0f;

    // Start next async conversion.
    tempSensors.requestTemperatures();

    // Thermal runaway protection.
    if (tempEnclosureA > TEMP_SAFETY_MAX || tempEnclosureB > TEMP_SAFETY_MAX) {
        if (!thermalRunaway) {
            Serial.println("ENV_CTRL: !!! THERMAL RUNAWAY DETECTED !!! Heaters killed.");
            thermalRunaway = true;
        }
        emergencyHeaterShutdown();
    }
}

void runTemperaturePID() {
    if (thermalRunaway) {
        emergencyHeaterShutdown();
        return;
    }

    unsigned long now = millis();
    float dt = (now - lastPidMs) / 1000.0f;
    lastPidMs = now;

    if (dt <= 0.0f || dt > 10.0f) {
        // Skip unreasonable dt (startup or overflow).
        return;
    }

    heaterPwmValue = tempPID.compute(tempSetpoint, tempEnclosureAvg, dt);

    uint8_t pwm = (uint8_t)heaterPwmValue;
    ledcWrite(HEATER_PWM_CH_A, pwm);
    ledcWrite(HEATER_PWM_CH_B, pwm);
}

void emergencyHeaterShutdown() {
    ledcWrite(HEATER_PWM_CH_A, 0);
    ledcWrite(HEATER_PWM_CH_B, 0);
    heaterPwmValue = 0.0f;
    tempPID.reset();
}

// ===========================================================================
// CO2
// ===========================================================================
void readCO2() {
    // Send polling command to SprintIR.
    // The SprintIR-6S in polling mode responds to "Z\r\n" with "Z XXXXX\r\n".
    co2Serial.print("Z\r\n");
}

void parseCO2Response() {
    // Expected format: "Z XXXXX" where XXXXX is CO2 in ppm * 10.
    // Example: "Z 05000" = 50000 ppm (filtered value).
    if (co2Buffer[0] == 'Z' || co2Buffer[0] == 'z') {
        // Find the numeric part after space.
        char *numStart = co2Buffer + 1;
        while (*numStart == ' ') numStart++;

        long raw = atol(numStart);
        if (raw > 0) {
            co2Ppm = (int32_t)(raw * 10);  // SprintIR reports ppm/10
            co2LastReadMs = millis();
        }
    }
}

void runCO2Control() {
    unsigned long now = millis();

    // Safety: close solenoid if no valid reading for 30 seconds.
    if (now - co2LastReadMs > CO2_SENSOR_TIMEOUT_MS) {
        if (co2SolenoidOpen) {
            Serial.println("ENV_CTRL: CO2 sensor timeout - closing solenoid (safety)");
            digitalWrite(PIN_CO2_SOLENOID, LOW);
            co2SolenoidOpen = false;
        }
        return;
    }

    // Bang-bang with hysteresis.
    if (co2Ppm < co2LowPpm && !co2SolenoidOpen) {
        digitalWrite(PIN_CO2_SOLENOID, HIGH);
        co2SolenoidOpen = true;
    } else if (co2Ppm > co2HighPpm && co2SolenoidOpen) {
        digitalWrite(PIN_CO2_SOLENOID, LOW);
        co2SolenoidOpen = false;
    }
}

void setCO2Setpoint(float pct) {
    co2Setpoint = pct;
    // Recalculate hysteresis thresholds: +/- 0.2% around setpoint.
    int32_t centerPpm = (int32_t)(pct * 10000.0f);
    co2LowPpm  = centerPpm - 2000;  // setpoint - 0.2%
    co2HighPpm = centerPpm + 2000;  // setpoint + 0.2%
    Serial.print("ENV_CTRL: CO2 setpoint = ");
    Serial.print(pct, 1);
    Serial.print("% (low=");
    Serial.print(co2LowPpm);
    Serial.print(" high=");
    Serial.print(co2HighPpm);
    Serial.println(" ppm)");
}

// ===========================================================================
// Humidity
// ===========================================================================
void readHumidity() {
    if (!bmeAvailable) return;

    bme.takeForcedMeasurement();
    humidity = bme.readHumidity();
    bmeTemp  = bme.readTemperature();

    if (humidity < HUMIDITY_WARNING_MIN) {
        Serial.print("ENV_CTRL: WARNING - Low humidity: ");
        Serial.print(humidity, 1);
        Serial.println("% RH (check water tray)");
    }
}

// ===========================================================================
// Rocker Platform
// ===========================================================================
void setServoAngle(int angleDeg) {
    // Map angle (-10..+10) to servo microseconds.
    // Center = 1500us. 10 degrees ~ 55us (500us / 90deg * 10deg).
    int us = SERVO_CENTER_US + (int)((float)angleDeg * ((float)SERVO_RANGE_US / 90.0f));
    rockerServo.writeMicroseconds(us);
    rockerAngle = angleDeg;
}

void updateRocker() {
    unsigned long now = millis();

    // Check pause signal from motion controller.
    bool pauseSignal = digitalRead(PIN_PAUSE) == HIGH;

    if (pauseSignal && !rockerPaused) {
        // Entering pause: smoothly return to center.
        rockerPaused = true;
        rockerInTransition = true;
        rockerTransitionFrom = rockerAngle;
        rockerTransitionStartMs = now;
    } else if (!pauseSignal && rockerPaused) {
        // Exiting pause: resume from center to current target.
        rockerPaused = false;
        rockerInTransition = true;
        rockerTransitionFrom = ROCKER_CENTER;
        rockerTransitionStartMs = now;
        // Reset phase timer so we get a full hold after transition.
        rockerPhaseStartMs = now + ROCKER_TRANSITION_MS;
    }

    // Handle smooth transitions.
    if (rockerInTransition) {
        unsigned long elapsed = now - rockerTransitionStartMs;
        int target = rockerPaused ? ROCKER_CENTER : rockerTargetAngle;

        if (elapsed >= ROCKER_TRANSITION_MS) {
            // Transition complete.
            setServoAngle(target);
            rockerInTransition = false;
        } else {
            // Linear interpolation.
            float progress = (float)elapsed / (float)ROCKER_TRANSITION_MS;
            // Smoothstep for less jerky motion.
            progress = progress * progress * (3.0f - 2.0f * progress);
            int angle = rockerTransitionFrom +
                        (int)((float)(target - rockerTransitionFrom) * progress);
            setServoAngle(angle);
        }
        return;
    }

    // If paused, stay at center.
    if (rockerPaused) {
        return;
    }

    // Normal rocking pattern: hold at current position for ROCKER_HOLD_MS,
    // then transition to opposite side.
    if (now - rockerPhaseStartMs >= ROCKER_HOLD_MS) {
        // Time to switch sides.
        rockerPhasePositive = !rockerPhasePositive;
        rockerTargetAngle = rockerPhasePositive ? ROCKER_ANGLE_MAX : ROCKER_ANGLE_MIN;

        // Start smooth transition.
        rockerInTransition = true;
        rockerTransitionFrom = rockerAngle;
        rockerTransitionStartMs = now;
        rockerPhaseStartMs = now + ROCKER_TRANSITION_MS;
    }
}

// ===========================================================================
// Peltier Reservoir Control
// ===========================================================================
void runPeltierControl() {
    // Warm reservoir: on/off with 1C hysteresis.
    if (tempWarm > -100.0f) {  // sensor connected
        if (tempWarm < PELTIER_WARM_SETPOINT - PELTIER_HYSTERESIS) {
            if (!peltierWarmOn) {
                digitalWrite(PIN_PELTIER_WARM_EN, HIGH);
                peltierWarmOn = true;
            }
        } else if (tempWarm > PELTIER_WARM_SETPOINT + PELTIER_HYSTERESIS) {
            if (peltierWarmOn) {
                digitalWrite(PIN_PELTIER_WARM_EN, LOW);
                peltierWarmOn = false;
            }
        }
    } else {
        // Sensor disconnected: turn off for safety.
        digitalWrite(PIN_PELTIER_WARM_EN, LOW);
        peltierWarmOn = false;
    }

    // Cold reservoir: on/off with 1C hysteresis.
    if (tempCold > -100.0f) {  // sensor connected
        if (tempCold > PELTIER_COLD_SETPOINT + PELTIER_HYSTERESIS) {
            if (!peltierColdOn) {
                digitalWrite(PIN_PELTIER_COLD_EN, HIGH);
                peltierColdOn = true;
            }
        } else if (tempCold < PELTIER_COLD_SETPOINT - PELTIER_HYSTERESIS) {
            if (peltierColdOn) {
                digitalWrite(PIN_PELTIER_COLD_EN, LOW);
                peltierColdOn = false;
            }
        }
    } else {
        // Sensor disconnected: turn off for safety.
        digitalWrite(PIN_PELTIER_COLD_EN, LOW);
        peltierColdOn = false;
    }
}

// ===========================================================================
// Serial Reporting
// ===========================================================================
void printStatusReport() {
    // Format: ENV: T=37.1C CO2=5.1% RH=87% ROCK=+10 WARM=37.0C COLD=4.2C PAUSE=0
    Serial.print("ENV: T=");
    Serial.print(tempEnclosureAvg, 1);
    Serial.print("C CO2=");
    Serial.print((float)co2Ppm / 10000.0f, 1);
    Serial.print("% RH=");
    Serial.print(humidity, 0);
    Serial.print("% ROCK=");
    if (rockerAngle >= 0) Serial.print("+");
    Serial.print(rockerAngle);
    Serial.print(" WARM=");
    Serial.print(tempWarm, 1);
    Serial.print("C COLD=");
    Serial.print(tempCold, 1);
    Serial.print("C PAUSE=");
    Serial.println(rockerPaused ? "1" : "0");
}
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

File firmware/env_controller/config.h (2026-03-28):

/*
 * config.h — Pin definitions, setpoints, and tuning constants
 * LaminarForge Incubation Enclosure Environmental Controller
 * Target: ESP32-S3 DevKitC (separate from FluidNC motion controller)
 */

#ifndef CONFIG_H
#define CONFIG_H

// ---------------------------------------------------------------------------
// GPIO Pin Assignments
// ---------------------------------------------------------------------------

// DS18B20 1-Wire bus (enclosure sensors + reservoir sensors share this bus)
#define PIN_ONEWIRE           4

// Enclosure heater MOSFET PWM outputs (25 kHz)
#define PIN_HEATER_A          5
#define PIN_HEATER_B          6

// SprintIR-6S-5 CO2 sensor UART
#define PIN_CO2_RX           15   // ESP32 RX <- SprintIR TX
#define PIN_CO2_TX           16   // ESP32 TX -> SprintIR RX

// CO2 solenoid valve MOSFET (digital on/off)
#define PIN_CO2_SOLENOID      7

// BME280 I2C (humidity monitoring)
#define PIN_I2C_SDA           8
#define PIN_I2C_SCL           9
#define BME280_I2C_ADDR    0x76

// MG996R rocker servo PWM
#define PIN_SERVO            10

// Pause signal from motion controller (active HIGH = pause)
#define PIN_PAUSE            11

// Peltier H-bridge control (L298N)
// Warm reservoir
#define PIN_PELTIER_WARM_EN  12   // PWM enable (on/off)
#define PIN_PELTIER_WARM_IN1 13   // Direction pin 1
#define PIN_PELTIER_WARM_IN2 14   // Direction pin 2

// Cold reservoir
#define PIN_PELTIER_COLD_EN  17   // PWM enable (on/off)
#define PIN_PELTIER_COLD_IN1 18   // Direction pin 1
#define PIN_PELTIER_COLD_IN2 21   // Direction pin 2

// ---------------------------------------------------------------------------
// PWM Configuration
// ---------------------------------------------------------------------------
#define HEATER_PWM_FREQ     25000  // 25 kHz for MOSFET switching
#define HEATER_PWM_RES          8  // 8-bit resolution (0-255)
#define HEATER_PWM_CH_A         0  // LEDC channel for heater A
#define HEATER_PWM_CH_B         1  // LEDC channel for heater B
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

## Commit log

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2026-03-19 Add PCB layout system, microfluidic chip Rev B, and new CAD models
    - Rust PCB layout generator (src/pcb/) with KiCad export, Freerouting
    DSN/SES integration, autorouter, DRC validation, and gerber output
    - CNC microfluidic chip (16-chamber PMMA, ANSI/SLAS footprint) with
    Rev B geometry fixes: 2mm channels, 1.6mm ports, 3.18mm corner radii,
    cover plate alignment holes, centered label
    - Aluminum heating block replaces copper spreader + PETG tube holder
    - New bins: fcb_board, monolithic_board, tube_holder, tube_fit_test,
    pbmc_flow_cell_mount, primer_prep_rack, pad_positions, pcb_layout
    - Remove deprecated optical_mount
    - KiCad PCB project, LCSC component library, JLCPCB BOM/CPL
    [bom.csv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]
2026-03-19 Add STEP file export for microfluidic chip via OpenCascade
    New binary microfluidic_chip_cnc_step generates .stp files with proper
    B-rep geometry for CNC shop submission. Same Rev B dimensions as STL
    version. Adds opencascade and glam dependencies.
    [microfluidic_chip_16ch_channel_plate.stp, microfluidic_chip_16ch_cover_plate.stp]
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2026-03-28 Add firmware and protocol suite for liquid handler robot
    FluidNC YAML config (4-axis: X/Y belt, Z geared belt, I syringe lead screw),
    environmental controller Arduino firmware (PID temp, CO2 bang-bang, rocker servo,
    Peltier reservoirs), wiring schematic, and 6 Python protocol scripts (deck
    calibration, media change, AAV transduction, cell harvest, G-code sender, config).
    [fluidnc_config.yaml]
2026-03-28 Fix Hamilton 1710RN dimensions from datasheet verification
    Barrel OD: 6.60mm → 7.75mm (6.6mm was the 1701/10μL model)
    Barrel length: 60mm → 65mm
    Flange width: 14mm → 12.5mm
    Part number: 81020 → 81030 (RN with beveled 22s needle)
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2026-03-30 Add turbine wheel design validation infrastructure — JSON spec + Rust tests
    Machine-readable design spec (design-specs/turbogen_turbine_wheel.json)
    stores all geometry, thermodynamic, and material parameters for the 75mm
    Inconel 713C turbine wheel. Rust integration tests compute 12 derived
    engineering quantities and assert they fall within published acceptable
    ranges. Tests cross-check JSON against lib.rs CAD constants to catch drift.
    Validation points: velocity ratio, loading/flow coefficients, diameter
    ratios, Glassman blade count, degree of reaction, bore stress with safety
    factor, tip clearance thermal growth (Al/steel housing), exit continuity,
    specific speed (Rohlik SI dimensionless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
2026-03-30 Add centrifugal disk expansion to tip clearance tests
    Tip clearance analysis was only accounting for thermal CTE growth.
    Added centrifugal radial expansion of rotor tip per Kumar et al. (2020):
    delta_R = (rho * omega^2 * R^3 * (1-nu)) / (4*E) using hot modulus.
    Centrifugal growth is ~0.042mm (small vs 0.341mm thermal), but tightens
    clearance from 0.428->0.385mm (Al) and 0.356->0.313mm (steel). Both
    still positive, no rub risk with 0.5mm cold clearance.
2026-03-30 Rewrite turbine wheel CAD: smooth NURBS loft blades + revolved hub
    Replaces discrete CSG construction (stacked cylinders + boxes) with
    proper B-Rep geometry for foundry-ready STEP output:
    - Hub disc: Face::revolve() of 9-point meridional profile instead of
    15 stacked cylinders. Produces exact solid of revolution. Shaft bore
    integral to profile (no boolean subtract).
    - Blades: Solid::loft() through 21 quadrilateral Wire cross-sections
    instead of 10 box/cylinder primitives. Produces smooth NURBS surfaces
    via BRepOffsetAPI_ThruSections. Each station wire has 4 edges
    (hub-PS, shroud-PS, shroud-SS, hub-SS) with consistent CCW winding.
    - LE taper: smooth linear transition from 1.0mm t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
2026-03-30 Add blade-root fillets + casting design fixes for turbine wheel
    - Selective edge filleting: identify 82 blade-root intersection edges
    by hub contour proximity + length filter, fillet at R0.5mm
    - LE thickness 1.0→1.2mm (Inconel 713C casting minimum)
    - Tip clearance 0.5→0.6mm cold (thermal margin with Al housing)
    - Housing bore 76.0→76.2mm (matches new clearance)
    - STEP output: 42,592 entities with smooth fillet surfaces
    - All 14 validation tests passing
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2026-03-30 Add complete RFQ package for turbine wheel investment casting
    Casting spec (LF-TW-SPEC-001 Rev A), RFQ email template, foundry
    shortlist (PBS, Aristo Cast, Barron, BasTech, ZHY), and drawing notes.
    Package is ready to send with the STEP file for quotes.
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2026-04-09 Rewrite microlattice swab to match spec: 150mm total, 80mm breakpoint, tapered tip
    Fix critical geometry issues in the microlattice swab CAD model:
    - Total length: 80mm -> 150mm (matches literature standard)
    - Breakpoint: 75mm -> 80mm from tip (per spec + literature range 70-80mm)
    - Head: cylindrical -> tapered cone (2.6mm tip -> 3.0mm base) for genital
    mucosal anatomy instead of nasopharyngeal cavity
    - Head length: 15mm -> 18mm (mid-range of literature 15-20mm)
    - Unit cell: 1.0mm -> 0.8mm (better capillary action within 0.5-1.0mm range)
    - Added neck taper: 3mm transition from head base to shaft (per literature)
    - Fixed inverted taper cone (was narrow-end meeting wide head)
    - Simplified s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
2026-04-11 Complete reservoir tray: add tube routing notches, per-pocket labels, fix material to PLA
    Closes T-DD17E865. Added U-shaped tube routing notches on back wall
    for silicone tubing egress, replaced single label slot with 3 per-pocket
    label recesses, corrected material from PETG to PLA per spec. Updated
    header to document this as a bench development fixture for v1 LAMP
    fluid path testing (v2 will use lyophilized reagents).
2026-04-11 Add heated lid assembly for v1 LAMP device
    Two-part design replacing mineral oil overlay for evaporation prevention:
    - Aluminum heated plate (84×26×6mm) with Kapton heater recess, thermistor
    pocket, magnet closure, and M3 hinge mounting holes
    - PETG hinge frame (70×20×15mm) U-bracket with hinge pins and enclosure
    mount holes
    Exports: heated_lid_plate.stl, heated_lid_frame.stl
    Ticket: T-2BE16750
2026-04-11 Remove obsolete dispensing system CAD models
    Deleted 10 files (syringe_motor_mount, syringe_plunger_pusher,
    syringe_pump_cradle, dispensing_frame, dispensing_carriage,
    outlet_valve_mount, reservoir_tray, waste_tray, rail_mounts,
    capping_arm) and their STL outputs. Removed orphaned SILICONE/PTFE
    constants from lib.rs. Kept syringe_pump_standalone (independent
    design for microfluidic chip work).
    Dispensing hardware replaced by pre-loaded lyophilized consumable
    tubes — see decision artifact A-E46A1C6B.
2026-04-12 Remove dead dispensing hardware code from assembly and delete primer_prep_rack
    Post-lyophilization pivot cleanup (A-E46A1C6B). The fluid-handling
    slice was replaced with consumable-design — all motorized dispensing
    hardware is gone.
    - assembly.rs: remove build_dispensing_frame, build_syringe_cradle,
    build_linear_rail, build_carriage functions and all positioning/
    print statements referencing them
    - Delete primer_prep_rack.rs (clipped onto dispensing frame, entirely dead)
    - Keep syringe_pump_standalone.rs and lib.rs constants (used for chip work)
2026-04-13 Redesign optical mount for OPT101P DIP-8 package (T-673C57B1)
    - Increase SLOT_SPACING from 10mm to 12mm to accommodate OPT101P DIP-8
    body (9.81mm along pin direction doesn't fit at 10mm)
    - Create new optical_mount.rs with:
    - 8x 5.2mm press-fit LED holes on front face
    - 8x rectangular recesses (10.4x10x5mm) for OPT101P on back face
    - 8x vertical tube channels (7mm, open-top) for PCR tube pass-through
    - 8x 3mm optical apertures connecting LED to detector through tube
    - Wire routing channel (3mm x 2.5mm) along bottom back face
    - Light-tight divider walls (1.6mm) between adjacent slots
    - M3 mounting holes aligned with heating block pattern
    - Add shared optical mount constants to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
2026-04-22 Add imaging_gantry.rs: 2-axis gantry for in-incubator readout of 100 chips
    Option A architecture: single camera + dual-mode illumination head on an
    XY gantry mounted to the chip_incubator_v2 chamber ceiling. Scans all
    100 Rev C chips in ~6 min (target: 15 min kinetic window).
    Geometry:
    - 2040 V-slot + MGN12H rails, 520 mm X-beam, 480 mm Y-beam
    - Y-rails 460 mm apart, 5 mm below ceiling
    - 80 mm Ø × 80 mm cylindrical head, 160 mm drop column
    - 50 × 50 × 1.1 mm ITO-coated heated window (anti-condensation, 2.5 W)
    - Dual illumination: CRI-90 white ring (LAMP colorimetric) + 470 nm
    blue spots (SYTO-9 fluorescence) with flip-in 520 nm LP filter
    - Working distance 87 mm (top she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
2026-04-22 Add liquid handler integration CAD stub (lh_interface)
    Models the mechanical interface between the 100-chip rack and a
    commercial liquid handler (Opentrons Flex reference):
    - Clamshell motorized top hatch (2x MG996R servos)
    - Telescoping per-shelf linear rail (200 mm extension)
    - Solenoid-driven detent locking pins (home + deployed)
    - Reflective fiducial L-frame for LH camera homing
    - Emits 100-chip ANSI/SLAS coordinate table and 12.5 min cycle budget
    Ticket T-4106BECC.
2026-04-22 Add controller_pcb bin for chip_incubator_v2 thermal container
    New 2-layer 100x80mm PCB housed in external control box next to the
    thermal container. Implements the firmware spec from artifact
    A-E798C84D: ESP32-S3-WROOM-1 MCU, SHT40 (I2C), MH-Z19B (UART),
    DS18B20 (1-Wire), Crydom SSR trigger for the 200W PTC heater, IRLZ44N
    for 12V blower fan + CO2 solenoid, G6K EMR alt path, TMC2209 6-pin
    breakout header, KSD9700 100C thermostat as independent safety
    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
    [controller.dsn, controller.kicad_pcb, controller_bom.csv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]
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2026-04-22 Add hil_harness skeleton for Phase 6 LH handshake testing
    Reference implementation of the MQTT handshake between a simulated
    liquid handler and the ESP32-S3 controller, supporting the 100-chip
    Rev C HIL validation plan (T-6E2C8835, artifact A-558A7D10).
    - Pure stdlib skeleton: command enum, per-cycle sequencer, jsonl logger
    - Honors topic scheme from A-71001BA1 and broker address from A-E798C84D
    - 2 unit tests covering sequence shape and topic formatting
    - CLI flags --broker, --cycles, --pipette-dwell-secs, --logfile
    - TODO markers where rumqttc AsyncClient hooks will slot in
    Does not add rumqttc as a dep yet — keeping the skeleton dep-free so
    the main workspace build stays small. The re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
2026-04-22 Add controller PCB JLCPCB fab package (v1, unrouted) + SES import flag
    Generate full Gerber/drill/BOM/CPL package for ESP32-S3 controller PCB from
    controller.kicad_pcb. Ships as an unrouted reference package: Freerouting
    2.1.0 headless CLI fails on this DSN with MazeSearchAlgo NPEs, never writes
    SES, and ignores -mp / max_passes / job_timeout. See artifact A-4220853D on
    ticket T-E9B4AB61 for the full autoroute attempt log and next-revision TODOs
    (placement overlaps at R1/R2/J1/L1/C2, manual Freerouting GUI run, thermal
    relief on regulator TABs).
    New in this commit:
    - pcb/output/controller_fab/controller_jlcpcb_v1.zip (51 KB, JLCPCB upload)
    - pcb/output/controller_fab/gerbers/ (F/B.Cu,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
    [controller-B_Cu.gbl, controller-B_Mask.gbs, controller-B_Silkscreen.gbo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]
2026-04-22 fix(controller-pcb): v2 — placement corrected, re-exported DSN, Freerouting converged, DRC clean
    Fixed 4 component placement bugs that caused v1 DRC failures:
    - R1, R2 (10K pull-ups): (42/58, 21) -> (42/58, 43), clears U1 ESP32-S3 pad row
    - J1 (barrel jack): (8, 8) -> (10, 5), clears U2 LM2596 pad row by 3.15mm
    - L1 (33uH inductor): (20, 13) -> (27, 11), clears U2 pad row and C1 pad 2
    - C2 (220uF output cap): (22, 22) -> (25, 28), clears U2 TAB by 2.7mm in x
    - C1 (220uF input cap): (18, 10) -> (36, 10), clears J1 pad 3 after J1 move
    Added GND copper-pour zones on F.Cu and B.Cu to the KiCad PCB writer so
    DRC can see GND plane connectivity (previously only in DSN, not kicad_pcb).
    connect_pa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
    [controller-B_Cu.gbl, controller-B_Mask.gbs, controller-B_Silkscreen.gbo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]
2026-04-22 Add system BOM v2 CSV — procurement-ready (T-73A81880)
    130-row BOM aggregating every component across Wave 1-3 subsystems:
    chip_stack_rack, chip_incubator_v2, rack_rocker, media_reservoir,
    imaging_gantry, lh_interface, controller_pcb + fab, BSC, PSUs, UPS.
    Categories: Structural, Thermal, Environmental, Rocker, Media delivery,
    Chips+consumables, PCB, PCB fab, Imaging, LH mechanics, Wiring+power,
    Software/misc, plus Tier-3 call-out.
    Core grand total: $18,041. All-in (ship 5% + duty 3% + contingency 10%):
    $21,288. Flex ($25k) and chip consumables are separately procured per
    task spec. See artifact A-B722A1A2 for summary markdown, lead-time
    critical path, and week-by-week ordering plan.
    [system_bom_v2.csv]
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2026-04-22 chip_farm_assembly_v2: full-system integrated assembly
    Integrates every subsystem from Waves 1-3 into a single visualization:
    container + rocker + rack + media reservoir + imaging gantry + LH
    interface + controller enclosure (placeholder) + tubing routing +
    cable routing. All 9 interference checks pass.
    T-20B7ECDD
    [chip_farm_assembly_v2.rs]
2026-04-22 Add cogs_model: 100/500/2000-chip scale COGS calculator (T-8D3EE16B)
    Pure-Rust CLI (std only) projecting per-chip, per-assay, per-campaign
    cost-of-goods at three scale tiers with sensitivity analysis and CSV
    dump. Subcommands: project / compare / sensitivity / csv.
    Baseline headline:
    Tier 1 (100/mo, $21k capex): $455.96/chip-campaign
    Tier 2 (500/mo, $90k capex): $422.41/chip-campaign
    Tier 3 (2000/mo, $108k walk-in):$408.72/chip-campaign
    Per-chip COGS is reagent-dominated (qPCR 20-gene = $200/chip = 49% of
    direct). Fixed costs (capex + facilities + labor) collapse to <$15/chip
    at Tier 3; further gains come from reagent strategy (qPCR sparsity,
    NanoString alt panel) and IM chip tra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
2026-04-22 Add 2-axis gimbal rocker for Rev D unidirectional flow
    Nested gimbal replacing rack_rocker.rs single-axis seesaw:
    - Outer ring pitches ±15° around X (1 cycle/min)
    - Inner plate rolls ±10° around Y (1/3 cycle/min)
    - 2× NEMA17 + 2× TMC2209 direct drive
    - 4× 6805-2RS deep-groove bearings
    - Igus E08 cable carrier for 2-axis flex
    - 45-chip sub-rack (reduced from 100) to fit 600×520×550mm container
    Interference check at ±15°/±10° extremes: 64mm X, 52mm Y, 91mm Z
    clearance. Required stand height 196mm to center pivot in container.
    Enables asymmetric-port unidirectional flow on Rev D chips per Busek
    2023. Ticket T-1C261EE3.
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2026-04-22 Add TEER readout daughter-board PCB for Rev D chip electrodes
    New PCB design that plugs into controller PCB v2 via 10-pin SPI header
    and reads integrated 4-wire Kelvin TEER electrodes + Pt1000 RTD on
    Rev D microfluidic chips (artifact A-2DFA1907).
    Components:
    - U1 AD5940 bioimpedance AFE (0.1 Hz-200 kHz, LFCSP-32, LCSC C650308)
    - U2/U3 ADG731 32:1 analog muxes (current/sense paths, TQFP-48, C579102)
    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
    [teer_readout-B_Cu.gbl, teer_readout-B_Mask.gbs, teer_readout-B_Silkscreen.gbo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]
2026-04-22 Add multi-organ chip-stack manifold (Rev D fluidic-via chaining)
    Parametric vcad model for a 3-5 chip stacking manifold (T-7CAFEB25).
    Chains Rev D chips via their integrated fluidic vias (1.5mm ID, 3mm
    O-ring seat per A-2DFA1907) with M3 shoulder-bolt + spring plungers
    (K=10 N/mm, 10N per via) and a 10-to-3mm cam lever loader.
    Modular builders: frame(), chip_pocket(), plunger_assembly(), o_ring(),
    cam_lever(), latch(), assembly(). Exports STL+STEP for all parts, emits
    dimensioned drawing + kinematic analysis, and verifies plunger force and
    Z-flatness in main() (PASS/FAIL).
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2026-05-11 Add LAMP Rev A PCBA workflow seed
    [lamp_rev_a.kicad_pcb]
2026-05-11 Advance LAMP Rev A schematic validation
    [lamp_rev_a.kicad_sch]
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2026-05-11 Lock LAMP Rev A placement contract
    [lamp_rev_a.kicad_sch]
2026-05-11 Materialize LAMP Rev A KiCad board
    [lamp_rev_a.kicad_pcb]
2026-05-11 Add LAMP Rev A pin net assignments
    [lamp_rev_a.kicad_pcb]
2026-05-11 Clean PCB outputs and stabilize LAMP Rev A placement
    [bom.csv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]
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2026-05-11 Move LAMP Rev A debug test points near ESP32
    [lamp_rev_a.kicad_pcb]
2026-05-11 Tighten LAMP Rev A routing workflow
    [lamp_rev_a.kicad_pcb]
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2026-05-11 Fix CAD clippy warnings
    [chip_farm_assembly.rs]
2026-05-11 Fix remaining CAD clippy warnings
2026-05-11 Fix CAD constructor clippy warnings
    [chip_farm_assembly.rs]
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2026-05-11 Fix XY carriage clippy warnings
2026-05-11 Fix controller PCB and release clippy warnings
2026-05-11 Fix chip farm assembly clippy warnings
    [chip_farm_assembly.rs]
2026-05-11 Fix still air box rail clippy warning
2026-05-11 Fix FCB board clippy newline warnings
2026-05-11 Fix chip farm v2 clippy loops
    [chip_farm_assembly_v2.rs]
2026-05-11 Fix monolithic board clippy warnings
2026-05-11 Fix XY carriage doc clippy warning
2026-05-11 Fix monolithic board clippy loops
2026-05-11 Fix fcb board clippy loops
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2026-05-12 Replace stale LaminarForge nonprofit CAD references
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2026-05-13 Add LAMP Rev A assembly fixture readability gate
    [lamp_rev_a.kicad_pcb]
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2026-05-27 Add chip priming tubing fixture CAD
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2026-05-27 Add closed incubator power failure holdover witness station
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2026-05-27 Add closed connector cap-loss prevention station CAD generator
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2026-05-27 Add cassette orientation error station CAD generator
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2026-05-27 Add sensor clock drift resync challenge station
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2026-05-27 Add incubator CO2 sensor zero span drift station
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2026-05-27 Add closed degas wetout leak station CAD
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2026-05-27 Add abort safe-state culture fixture CAD generator
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2026-05-27 Add flow sensor drift voting station CAD
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2026-05-27 Integrate closed validation CAD batch 25
    Register ten closed cell-culture validation stations in the equipment manifest and verifier.
    Add design-matrix and reproducibility-control notes for Batch25 validation modules.
    Drop generated STL blobs accidentally staged by worker branches and fix the sampling-bag deadleg datum sentinel geometry.
    [closed_culture_media_sampling_bag_deadleg_flush_station_assembly.stl, closed_culture_media_sampling_bag_deadleg_flush_station_barcode_coa_custody_lands.stl, cl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]
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2026-05-29 Fix LaminarForge CAD CI lint gate
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2026-05-31 Redesign LAMP CAD around sealed cartridge
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2026-06-04 Add 16-slot cassette A7 validation fixture spec
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2026-06-05 Reduce connector coupon print warping
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2026-06-27 Add 16-slot no-cell validation fixture CAD
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2026-07-01 Resolve Rev B controller PCBA selection blockers
    [lamp_rev_b_controller.kicad_pcb, lamp_rev_b_controller.kicad_sch]
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2026-07-01 Reduce Rev B controller routing to 172 unconnected
    [lamp_rev_b_controller.kicad_pcb]
2026-07-01 Reduce Rev B controller routing to 159 unconnected
    [lamp_rev_b_controller.kicad_pcb]
2026-07-01 Reduce Rev B controller routing to 149 unconnected
    [lamp_rev_b_controller.kicad_pcb]
2026-07-01 Reduce Rev B controller routing to 144 unconnected
    [lamp_rev_b_controller.kicad_pcb]
2026-07-01 Reduce Rev B controller routing to 138 unconnected
    [lamp_rev_b_controller.kicad_pcb]
2026-07-02 Reduce Rev B controller routing to 133 unconnected
    [lamp_rev_b_controller.kicad_pcb]
2026-07-03 Reduce Rev B controller routing to 123 unconnected
    [lamp_rev_b_controller.kicad_pcb]
2026-07-03 Reduce Rev B controller routing to 119 unconnected
    [lamp_rev_b_controller.kicad_pcb]
2026-07-03 Reduce Rev B controller routing to 116 unconnected
    [lamp_rev_b_controller.kicad_pcb]
2026-07-03 Reduce Rev B controller routing to 111 unconnected
    [lamp_rev_b_controller.kicad_pcb]
2026-07-03 Reduce Rev B controller routing to 105 unconnected
    [lamp_rev_b_controller.kicad_pcb]
2026-07-03 Reduce Rev B controller routing to 100 unconnected
    [lamp_rev_b_controller.kicad_pcb]
2026-07-03 Reduce Rev B controller routing to 94 unconnected
    [lamp_rev_b_controller.kicad_pcb]
2026-07-03 Reduce Rev B controller routing to 91 unconnected
    [lamp_rev_b_controller.kicad_pcb]
2026-07-03 Reduce Rev B controller routing to 88 unconnected
    [lamp_rev_b_controller.kicad_pcb]
2026-07-03 Reduce Rev B controller routing to 87 unconnected
    [lamp_rev_b_controller.kicad_pcb]
2026-07-03 Reduce Rev B controller routing to 86 unconnected
    [lamp_rev_b_controller.kicad_pcb]
2026-07-03 Reduce Rev B controller routing to 85 unconnected
    [lamp_rev_b_controller.kicad_pcb]
2026-07-03 Reduce Rev B controller GND unconnected count to 78
    [lamp_rev_b_controller.kicad_pcb]
2026-07-03 Reduce Rev B controller unconnected count to 76
    [lamp_rev_b_controller.kicad_pcb]
2026-07-03 Reduce Rev B controller unconnected count to 75
    [lamp_rev_b_controller.kicad_pcb]
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2026-07-07 Fix Rev B board bounds checks
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2026-07-08 Close HEATER0_PWM U6 route on Rev B controller
    [lamp_rev_b_controller.kicad_pcb]
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2026-07-09 Close USB_DP Rev B route open
    Add usb_dp_j1_to_bcu_trunk_bridge and v_usb_dp_j1_bcu_escape to the Rev B controller routing seed, then materialize the canonical board.
    Evidence: A-EDE7F629
    [lamp_rev_b_controller.kicad_pcb]
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2026-07-10 Reconcile Rev B ERC and fab release blockers
    [lamp_rev_b_controller.kicad_sch]
2026-07-10 Reconcile Rev B BOM and CPL fabrication classes
    [lamp_rev_b_controller.kicad_pcb, lamp_rev_b_controller.kicad_sch]
2026-07-10 Resolve Rev B controller U1 exposed pad grounding
    [lamp_rev_b_controller.kicad_pcb, lamp_rev_b_controller.kicad_sch]
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2026-07-29 Correct Rev B Seeed BOM catalog aliases
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2026-09-12 Move priming fixture parameters to runtime TOML and measure targeted CAD iteration
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2026-09-13 Correct local CAD workflow guidance and record model and tooling audit
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2026-09-23 Replace integral cassette housing with stock-plate Rev D frame
    Define bolted and doweled roof, sides and bezel with validated runtime joint parameters. Update individual and assembly drawings, BOMs, stock guidance and supplier replies. Verify joint hardware clearance and reject incompatible dimensions.
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

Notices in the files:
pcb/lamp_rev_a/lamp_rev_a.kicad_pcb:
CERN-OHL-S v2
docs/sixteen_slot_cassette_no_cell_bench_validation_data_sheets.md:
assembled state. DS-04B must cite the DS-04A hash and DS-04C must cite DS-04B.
